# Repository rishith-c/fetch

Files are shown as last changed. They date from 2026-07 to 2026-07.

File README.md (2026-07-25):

# FETCH

FETCH is a mecanum-wheeled robot that carries a trash can around a gallery and
comes to you when you call it. We built it in eight hours at a hackathon, and
it won first place.

You teach it a room by driving it around once. Park it on a spot, press a
button to name that spot, drive to the next one, name that. From then on it
drives to any of them on its own. A visitor calls it by opening a web page and
pointing their phone at the AprilTag beside them.

There is no lidar on this robot. No encoders, no IMU, and no map of the room.
That was not a design goal, it was the parts budget, and working around it is
most of what makes the project interesting.

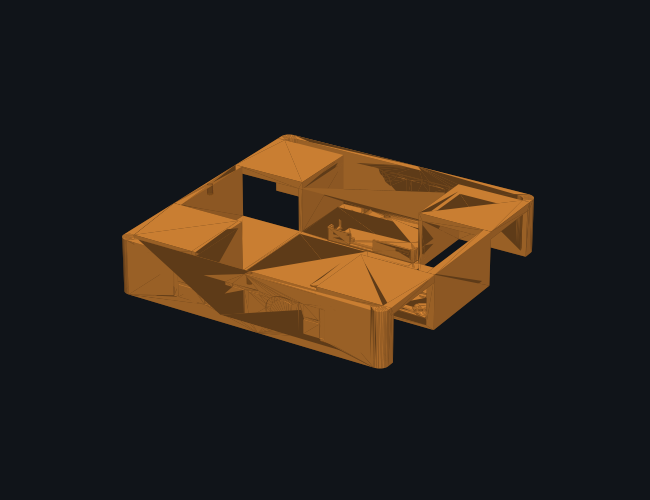
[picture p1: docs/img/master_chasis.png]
chassis


## The navigation problem

A robot with no encoders cannot know where it is. You might think you could
count motor steps and integrate, but mecanum wheels slip sideways as part of
how they generate lateral motion, so those counts diverge from reality within
a metre or two.

So we do not store positions. We store driving.

```
home ──teach──> tag 0 ──teach──> tag 1 ──teach──> tag 2
     <──────────        <──────────       <──────────
```

Nodes are places. Edges are the actual velocity commands you gave while
driving between them, saved as `(vx, vy, w, dt)` tuples. Press "mark 0" and
everything you drove since the last mark becomes the edge into node 0.

The nice part is that edges run both ways for free. To drive an edge backwards
you replay its segments in reverse order with every velocity negated. That is
a true inverse here, and we checked: net displacement of forward plus backward
comes out to exactly zero. It only works because the robot is holonomic. Try
this on a car and you will drive into a wall.

Route planning is Dijkstra weighted by recorded driving seconds. We started
with breadth-first search over hop count and it kept choosing one long edge
over two short ones, which looked broken to anyone watching.

## Calling the robot

Open `/user` on a phone, point the camera at a tag, press the button. The page
sends camera frames to the Pi, which runs the AprilTag detector and answers
with which checkpoint you are standing at. The robot then drives to you from
wherever it happens to be.

Detection runs on the Pi rather than in the browser, which is why this works
on any phone with no app and no install. The phone only needs a camera and a
fetch call.

## Hardware

| Part | What we used |
|---|---|
| Compute | Raspberry Pi 4 on its own 5 V power bank |
| Motion | Arduino Uno R4 WiFi, CNC Shield V3, four A4988 drivers |
| Motors | Four NEMA 17 steppers, 60 mm mecanum wheels |
| Sensing | USB webcam, three front-facing HC-SR04 |
| Power | 3S LiPo for motors, switched separately from the Pi |

The Pi and the motors run on separate supplies on purpose. Killing motor power
mid-demo should not take down the computer, the web server, and your only way
of stopping the robot.

Motor wiring:

| Corner | Socket | Step | Dir | Polarity |
|---|---|---|---|---|
| Front left | X | D2 | D5 | +1 |
| Front right | Y | D3 | D6 | +1 |
| Rear left | Z | D4 | D7 | -1 |
| Rear right | A | D12 | A0 | +1 |

Rear right takes its direction signal from A0 on a jumper wire rather than the
usual pin.

## Printed parts

Five parts, about five hours of printing all together, which ran while we
wrote firmware. The chassis is the long pole by a wide margin, so print that
one first and do everything else while it runs.

| | Part | Size (mm) | Print time | Filament |
|---|---|---|---|---|
|  | Master chassis | 210 x 210 x 55 | 3 h 51 m | 221 cm3 |
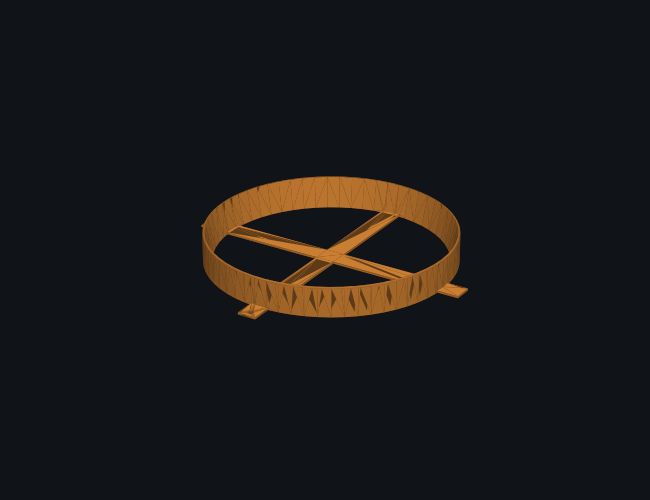
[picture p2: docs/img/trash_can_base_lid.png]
|  | Trash can base lid | 214 x 214 x 30 | 47 m | 48 cm3 |
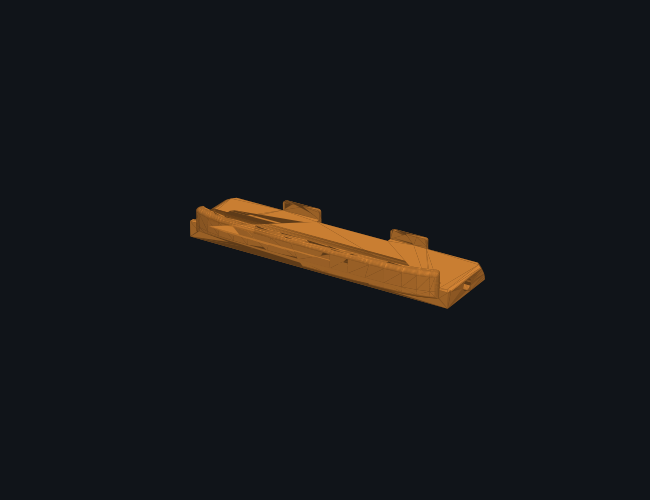
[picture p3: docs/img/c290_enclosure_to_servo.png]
|  | C290 enclosure to servo | 93 x 28 x 15 | 11 m | 9 cm3 |
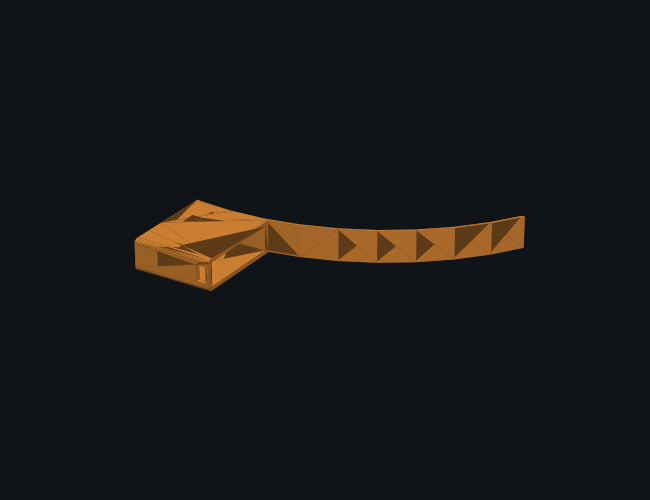
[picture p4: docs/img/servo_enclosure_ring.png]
|  | Servo enclosure ring | 106 x 88 x 16 | 10 m | 8 cm3 |
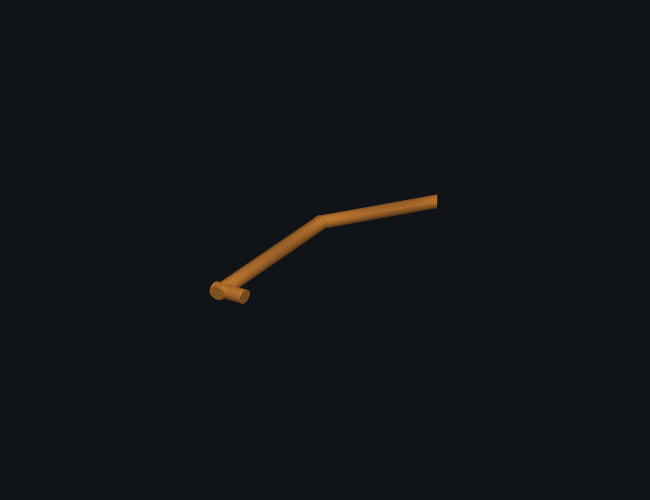
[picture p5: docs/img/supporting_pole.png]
|  | Supporting pole | 24 x 81 x 5 | 1 m | 1 cm3 |

Times are what our printers actually did at 0.3 mm layers and 15 percent
infill. A slower machine will take considerably longer, so slice before you
commit to a schedule.

## How much of this was fixed with a knife

We modeled these in a hurry and it shows. Roughly 80 percent of the parts
needed cutting or modifying by hand before they would fit. Holes drilled out,
walls trimmed, mounting faces filed back. Print quality was poor at the speed
we ran, so tolerances that would have been fine on a careful print were not
close enough to assemble.

Three of the four chassis joints needed super glue and repair work to hold.
The robot that won is held together partly with adhesive and partly with
patience.

Some features did not survive at all. The camera was supposed to sit on a tilt
servo so it could sweep to find a tag and then hold it centred. The mount
never fit properly, the servo never moved reliably, and we cut the whole
feature and bolted the camera down at a fixed angle. That turned out fine, and
arguably better, since a fixed camera is one less thing to fail mid demo.

If you are rebuilding this, dry fit the chassis before committing to the rest.
Most of what we cut by hand was avoidable with one test print and an hour of
tolerance work.

## Software

Three languages, each where it belongs.

Step timing lives on the Arduino in C++, because steppers need pulses at
precise intervals and Linux is not a real-time OS. A scheduler hiccup on the
Pi would stutter the motors. The Arduino does nothing else, so it never
hiccups.

Everything else is Python on the Pi: the web server, the checkpoint graph, the
route planner, and the vision. The web pages are HTML, CSS and JavaScript
embedded directly in `gui.py` as string constants.

The server is `http.server` from the Python standard library. No Flask, no
FastAPI, no build step. The whole thing is one file you copy with `scp`, and
on a fresh Pi it runs immediately. During a hackathon where the Pi got power
cycled repeatedly, that mattered more than any framework feature would have.

It has to be threaded because the camera stream at `/camera.mjpg` never
returns. It holds the connection open and writes JPEG frames forever, so a
single-threaded server would block there and stop answering everything else.
Five threads run in one process: HTTP handlers, the serial reader, a keepalive,
the camera, and the navigator.

One process rather than several, because only one process can hold
`/dev/ttyACM0` and only one can hold `/dev/video0`. Splitting autonomy into a
separate script would have meant stopping the GUI to demo, which is not a demo.

## Serial protocol

The Pi talks to the Arduino in plain text at 115200 baud.

```
v <vx> <vy> <w>   velocity, -100 to 100 each
m <corner> <spd>  drive one motor alone, 0=FL 1=FR 2=RL 3=RR
k <steps/s>       full scale wheel rate, for tuning stepper noise
g <0|1>           arm or disarm the front obstacle veto
s                 stop
?                 report state
```

Text rather than binary so you can debug it by opening a serial monitor and
typing. That saved us an hour when the rear right motor was misbehaving.

The Arduino reports `us f=52 lf=110 rf=0` in centimetres about eleven times a
second.

## Safety

Two of these live in firmware, which matters more than it sounds. The Pi
resends the current velocity every 100 ms, and if the Arduino goes 500 ms
without hearing anything it stops the motors. WiFi dropping, the browser
closing, the tunnel dying, or the Pi losing power all produce the same result:
the robot stops within half a second. The guarantee does not depend on the
network, because it is enforced by the side that is not on the network.

In precedence order:

1. The STOP button
2. Touching manual controls, which cancels any autonomous trip
3. The 500 ms communication watchdog, in firmware
4. Forward motion refused under 25 cm of front clearance, in firmware
5. Obstacle pause during route replay, which resumes rather than skipping

A sonar reading of `0` means no echo, not an obstacle. Both the firmware veto
and the replay loop require a reading that is close and physically plausible,
at least 3 cm, so a disconnected sensor cannot freeze the robot in place. We
learned this the hard way when a rail glitch pinned the front sensor at 5 cm
and forward motion stopped working entirely.

## Repository layout

```
firmware/fetch_final/   Arduino sketch: kinematics, sonar, safety
pi/gui.py               web server, both pages, all endpoints
pi/checkpoints.py       place graph, teaching, Dijkstra routing
pi/navigator.py         replays a planned chain of edges
pi/drive.py             serial to the Arduino, keepalive, auto reconnect
pi/fetch_auto.py        camera and AprilTag detection
cad/                    the five printed parts
markers/                printable tag36h11 tags, 0 through 4
bringup.sh              starts everything and prints both URLs
```

## Running it

```bash
./bringup.sh
```

This waits for the Pi, checks both services, reads the current tunnel URL, and
confirms both pages return 200 before printing anything. The services start
themselves at boot, so after a power cycle you only need this to find out what
URL the tunnel picked.

Print `markers/apriltags/apriltags_0-4.pdf` at 100 percent scale. Do not let
the print dialog scale it to fit the page, because the tag size is how the
robot judges distance.

## What it does not do

Replay is open loop, so every edge adds a few percent of distance error plus
some heading drift, and it compounds along a chain. The fix is teaching
checkpoints every couple of metres so no single edge is long enough to matter.

The robot has no spatial model, so it cannot work out that two checkpoints are
near each other unless you drove between them. If it insists on routing from 1
back through home to reach 0, drive it from 1 to 0 once and mark it. That edge
then exists in both directions.

Position is belief, not measurement. It updates when a trip completes, so an
aborted trip never claims an arrival, but picking the robot up and moving it
makes the belief wrong. Press Set HOME to correct it.

It does not plan around a moving crowd. It stops for obstacles and resumes.
That is honest for a supervised indoor space, which is what it was built for.

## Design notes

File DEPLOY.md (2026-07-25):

# FETCH — End-Product Software Deployment

Stepper build (NEMA17 + CNC Shield V3). One firmware, one Pi stack, one path.

## The software map

| Piece | File | Job |
|---|---|---|
| Firmware (THE one to flash) | `firmware/fetch_final/fetch_final.ino` | 4 steppers + 5 sonars + tilt servo + serial protocol + watchdog + front veto |
| Pi relay | `pi/fetch_relay.py` | phone WiFi vectors -> USB serial (phone-sees-robot homing) |
| Direct-path nav | `pi/topo_nav.py` | checkpoint graph router (BFS over verified segments) |
| Checkpoint server | `pi/topo_server.py` | iPhone QR destination -> AprilTag route -> drives the Uno |
| Bench tester | `pi/fake_phone.py` | simulates the phone stream, no app needed |
| Service installer | `pi/install_fetch_service.sh` | auto-start on boot via systemd |

## 1. Flash the firmware (from this Mac, robot USB-connected)

```bash
arduino-cli compile -b arduino:renesas_uno:unor4wifi ~/Developer/fetch/firmware/fetch_final
```

```bash
arduino-cli upload -b arduino:renesas_uno:unor4wifi -p /dev/cu.usbmodemB43A45B3E0482 ~/Developer/fetch/firmware/fetch_final
```

If upload fails: double-tap RESET (LED breathes) and retry.
Then Serial Monitor 115200: `f b l r q e s` drive keys, `t 120` tilts camera,
`us f=.. lf=..` lines stream distances.

## 2. SSH into the Pi

Enable once (SD card in this Mac): create an empty file named `ssh` on the
boot partition. Or on the Pi itself: `sudo raspi-config` -> Interface Options -> SSH.

```bash
ssh pi@raspberrypi.local
```

(Default password `raspberry` unless you changed it. If .local fails, find the
IP in your hotspot's client list and `ssh pi@<ip>`.)

## 3. Deploy the code to the Pi

```bash
scp -r ~/Developer/fetch/pi pi@raspberrypi.local:~/fetch
```

On the Pi (one time):

```bash
sudo apt update && sudo apt install -y python3-serial python3-opencv python3-pip && pip3 install pupil-apriltags --break-system-packages
```

## 4. Run it

Plug the Uno into the Pi via USB. Manual/bench test first:

```bash
python3 ~/fetch/fake_phone.py --approach
```

Phone-vision homing (the app streams to this):

```bash
python3 ~/fetch/fetch_relay.py
```

Direct-path checkpoint navigation (press-button-and-it-comes, out of sight):

```bash
python3 ~/fetch/topo_server.py --serial /dev/ttyACM0 --map ~/fetch/config/topo_map.demo.json --start-zone 0
```

## 5. Auto-start on boot (demo day)

```bash
bash ~/fetch/install_fetch_service.sh --serial /dev/ttyACM0 --start-zone 0 --dry-run
```

Re-run without `--dry-run` to install. Robot then boots straight into service.

## Protocol (Uno <-> Pi), for debugging

- Pi -> Uno: `v vx vy w\n` at up to 15 Hz (each -100..100), `t <deg>\n` tilt
- Uno -> Pi: `us f=52 lf=110 rf=200 lr=0 rr=88\n` at ~7 Hz (cm, 0 = no echo)
- Uno stops itself if `v` goes silent 500 ms (watchdog) and refuses forward
  motion under 25 cm front clearance (veto) — safety lives on the Uno.

## Wiring recap for fetch_final

- Motors (proven): FL=X(2,5) FR=Y(3,**A2**) RL=Z(4,7) RR=A(12,13), EN=8
- Sonars: TRIG all -> D9. Echoes: front D10, L-front A0, R-front A1,
  L-rear A3, R-rear A4
- Servo: signal D11, power from XL4015 @5.0V (never the Uno 5V), common GND
- POL / corner fixes: edit `POL[4]` and the four constructors at the top of
  fetch_final.ino only.

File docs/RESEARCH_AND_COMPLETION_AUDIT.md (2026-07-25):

# FETCH research and completion audit

Last software audit: 2026-07-23. Final selected prototype: TT mecanum chassis,
Uno R4, two L298N modules, two 6.5 V XL4015 rails, five HC-SR04 sensors, Pi 4
camera navigation, and the iPhone checkpoint app.

## Requirement interpretation

“Press a button when neither I nor the robot can see the other, and have the
robot come to me” is implemented as **checkpoint rendezvous**:

1. The person scans the QR on the nearest mapped poster.
2. The app sends that fixed checkpoint ID to the robot over private Wi-Fi.
3. The robot independently sees AprilTags with its forward camera and follows a
   pre-commissioned directed graph.
4. The person and robot never need line of sight to one another.
5. The final tag plus front-sonar range proves arrival at the poster.

This does not infer the phone's indoor coordinates and does not track a moving
person. That distinction is fundamental: without venue infrastructure, a phone
does not provide reliable mall-scale indoor position to this robot. A scanned
known checkpoint turns an underdetermined localization problem into a bounded
routing problem suitable for the hackathon.

## Research decisions

| Topic | Primary evidence | Decision in this build |
|---|---|---|
| Visual fiducials | [AprilTag 3 project](https://github.com/AprilRobotics/apriltag) documents small-tag improvements and OpenCV integration; [OpenCV ArUco detection](https://docs.opencv.org/4.x/d5/dae/tutorial_aruco_detection.html) provides dictionary-based marker detection. | Use OpenCV's built-in `DICT_APRILTAG_36h11` end-to-end so poster generation and Pi detection use the identical available family. Use a measured 180 mm tag and require route camera tests. |
| Camera geometry | Pinhole projection from the requested 1280 px width and assumed 70° horizontal FOV. | A 180 mm tag models as 54.8 px at 3 m. The Pi rejects a camera stream below 1280×720. Initial checkpoint spacing is 2–3 m; 5 m is only an experimentally proven extension. |
| Ultrasonic timing | [HC-SR04 datasheet](https://www.digikey.in/en/htmldatasheets/production/1979760/0/0/1/hc-sr04.html) specifies a 10 µs trigger, 40 kHz burst, nominal 2–400 cm range, and recommends a measurement cycle over 60 ms. | Trigger all five for 10 µs every 65 ms and capture all five echoes concurrently. Installed cross-talk testing remains mandatory. |
| Uno electrical/pins | [Arduino Uno R4 Minima datasheet](https://docs.arduino.cc/resources/datasheets/ABX00080-datasheet.pdf) identifies 5 V operation, PWM-capable pins, analog pins usable as GPIO, and per-pin current limits. | Use PWM D5/D6/D9/D10, eight other motor-direction GPIO, D3 shared trigger, and D11/A2–A5 echoes. L298 logic inputs—not motors—load the GPIO. |
| Motor driver loss | [ST L298 datasheet](https://www.st.com/resource/en/datasheet/l298.pdf) gives a typical total bridge drop of about 1.8 V at 1 A and larger worst-case drops, logic supply requirements, current limits, and thermal protection. | Two L298Ns are accepted because they are already selected, but they are inefficient and require measured current/heat. A 6.5 V driver rail yields about 4.7 V at a typical 1 A bridge load. |
| DC conversion | [XL4015 datasheet](https://www.xlsemi.com/datasheet/XL4015-EN.pdf) specifies an adjustable step-down regulator and headline 5 A capability under suitable implementation/thermal conditions. | Use two modules, one per L298N, never paralleled. Adjust each unloaded to 6.50 V and validate voltage and temperature under final load. Module marketing is not accepted as proof of continuous current. |
| Chassis/motors | [Hiwonder chassis listing](https://www.hiwonder.com/products/mecanum-wheel-smart-chassis-car) specifies four 3–6 V 1:120 TT motors, 120–240 RPM, 66 mm wheels, 180 × 140 × 89 mm chassis, and a claimed 1500 g capacity. | Treat 3–6 V and 1500 g as bounds that still require assembled payload and traction tests. |
| Pi power | [Raspberry Pi power documentation](https://www.raspberrypi.com/documentation/computers/raspberry-pi.html) specifies the Pi 4's recommended 5.1 V / 3 A supply. | Use a separate power bank for Pi/camera/Uno compute; keep noisy motor power on the battery/converters. Grounds meet through Pi USB→Uno→L298 logic. |
| iPhone local network | Apple requires a [local-network usage description](https://developer.apple.com/documentation/BundleResources/Information-Property-List/NSLocalNetworkUsageDescription) and documents [`NSAllowsLocalNetworking`](https://developer.apple.com/documentation/bundleresources/information-property-list/nsapptransportsecurity/nsallowslocalnetworking) for `.local`/local resources. | Generated Xcode project contains both keys. The app uses `http://fetch.local:8080` on a private demo router/hotspot. Internet-wide ATS is not disabled. |
| Battery connector | The pack seller has not supplied an independently verified BMS-current or connector-current specification. | Begin with a 3 A fuse, use only the matching charger, never parallel packs, measure real current/heat, and do not increase the fuse without exact component ratings. |

## Software evidence

`./verify_all.sh` currently proves:

- 13/13 deterministic pin, camera, stopping-envelope, runtime, converter, and
  L298 voltage calculations pass.
- 16/16 navigation, multi-hop out-of-sight routing, directed-graph, stale-data, arrival, obstacle, serial,
  heartbeat, and live HTTP API tests pass.
- `tt_fetch_drive.ino` compiles for Uno R4 Minima at 18% flash and 13% RAM.
- Pi server, navigation, and map tools compile; a sample graph validates.
- Swift source typechecks and the generated Xcode project builds for an iOS
  Simulator target with required permission keys.
- All 12 generated AprilTags detect and all 12 QR payloads decode.
- The README, verifier, firmware, Pi service, app, posters, and final manual all
  name the same two-L298N baseline.

These checks are authoritative evidence for software structure and deterministic
models only. They are not evidence of physical performance.

## Requirement-by-requirement status

| Objective requirement | Evidence | Status |
|---|---|---|
| App selects where the person is | QR parser accepts only `FETCH:<nonnegative id>`; generated posters encode matching payloads. | Software proven |
| Button summons while robot is out of sight | App `POST /come`; HTTP integration test; route runs from current checkpoint to requested ID without person/robot line of sight. | Software proven; venue route pending |
| Robot knows where it is | It starts at an operator-confirmed `--start-zone` and updates `at` only after gated tag arrival. Fresh visible tags support localization search. | Software proven; camera route pending |
| Robot knows how to reach every checkpoint | Directed BFS plus strong-connectivity validation. | Software proven; physical directed edges pending |
| Robot follows wall codes | OpenCV AprilTag detector, centered visual steering, 1280×720 preflight, regenerated tags. | Software proven; actual camera/lighting pending |
| Obstacle is not confused with arrival | Arrival requires correct tag area, centering, 65±12 cm sonar, and 0.35 s hold; close small-tag obstacle test passes. | Software proven; physical obstacle test pending |
| Loss of Pi commands stops motors | Uno 500 ms watchdog. | Code/compile proven; unplug test pending |
| Loss of camera/telemetry stops route | 0.5 s freshness checks and tests. | Software proven; hardware disconnect tests pending |
| Loss of phone stops route | 2 s server heartbeat watchdog and integration test. | Software proven; real Wi-Fi/app-background test pending |
| Two L298Ns and five sonars fit Uno | 18 unique GPIO signals, correct PWM set, no overlap, firmware compiled. | Proven electrically at signal-map level |
| Battery runs 20 minutes | Energy model predicts 32 minutes even at 3 A using 80% capacity. | Model only; loaded 20-minute run pending |
| Electrical path is safe enough for demo | Fused, switched, isolated motor rails, separate Pi rail, common ground, required capacitors/jumpers documented. | Design reviewed; measurements/thermal pending |
| Entire supervised hackathon demo works | 1–150 manual and go/no-go sheet define exact acceptance. | **Not yet proven physically** |

## Hard limits and residual risks

- HC-SR04 has no diagnostic distinction between open space and a disconnected or
  acoustically failed sensor; preflight targets and an operator cutoff are
  therefore required.
- Five simultaneous ultrasonic transmitters can cross-talk. If installed tests
  show unsafe false clears, the hardware must change; software cannot certify it.
- L298N voltage loss and TT stall current are highly load-dependent. The exact
  motor stall current and pack BMS rating remain unknown until measured/sourced.
- No wheel encoders or IMU exist. The robot can visually home between tags but
  cannot guarantee a metrically accurate path through an unmarked blind segment.
- The graph is only valid for the exact poster positions, camera height, lighting,
  and cleared straight segments that were commissioned.
- Guest mall Wi-Fi may isolate clients. Use a private travel router/hotspot whose
  full-route coverage has been tested.
- HTTP control is unauthenticated and intentionally limited to a private demo
  network. It is not a production security architecture.
- Five hobby sonars and software stops do not constitute certified personnel
  protection. Keep the route controlled and an operator on the physical switch.

## Completion rule

The objective is complete only after every blank in the final manual's go/no-go
record contains measured evidence from this exact assembled robot and every
source-to-destination summon passes in the actual demo layout. Until then the
correct claim is **software-verified, physically pending**.

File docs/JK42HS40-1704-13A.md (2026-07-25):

---
tags: [hardware, motor, final]
---
# JK42HS40-1704-13A

Final FETCH motor. Manufacturer: JKONGMOTOR.

| Specification | Value |
|---|---:|
| Type | NEMA17, 2-phase bipolar, 4-wire |
| Step angle | 1.8° = 200 steps/revolution |
| Rated current | 1.7A per phase |
| Phase resistance | 1.5Ω |
| Phase inductance | 2.3mH |
| Holding torque | 0.42Nm |
| Body | 42×42×40mm |
| Shaft | 5mm D-cut |
| Mass | approximately 280g |
| Manufacturer coil colours | A+: black, A−: green, B+: red, B−: blue |

Verify coil pairs with multimeter continuity even when colours match.

## A4988 setting

The 75% target is 1.275A. Vref remains:

| Sense resistor | Vref |
|---|---:|
| R050 | 0.510V |
| R100 | 1.020V |

Use forced airflow. Never connect or disconnect a motor while powered.

## Recalculated result

- Estimated acceleration under the project assumptions: approximately 4,000mm/s².
- Firmware slew: 500mm/s², approximately 8× conservative.
- The 2.3mH inductance gives ample margin at the final 250mm/s ceiling.

Source: [JKONGMOTOR manufacturer specification](https://www.jkongmotor.com/nema-17-jk42hs40-1704-13a-hybrid-stepper-motor.html).

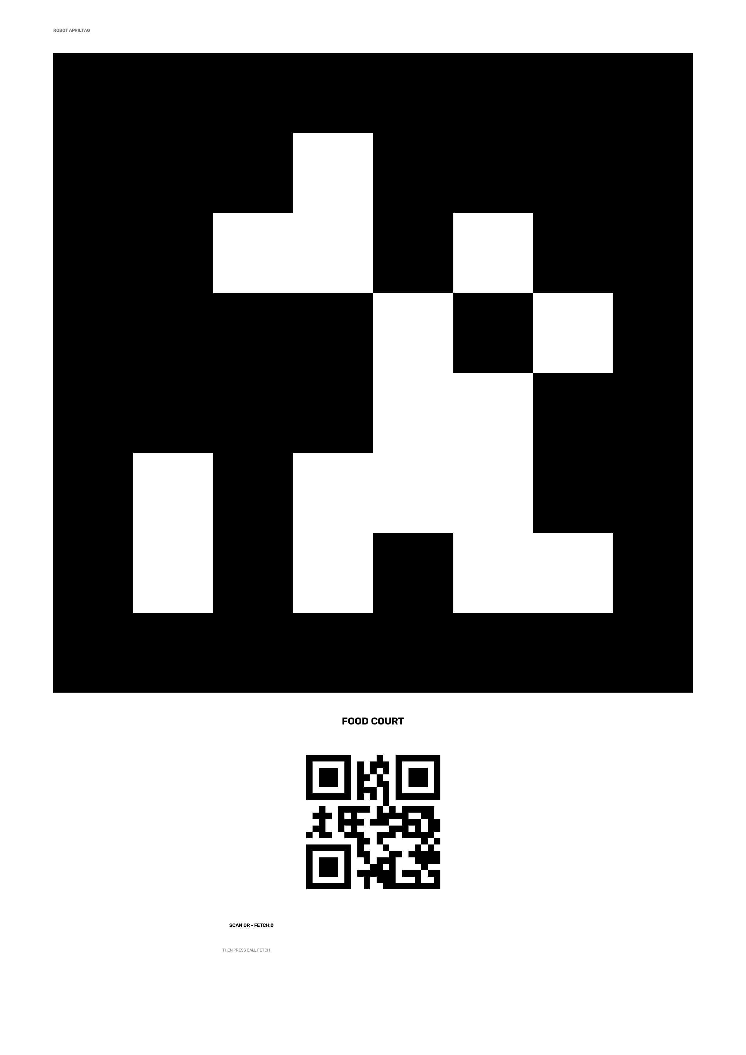
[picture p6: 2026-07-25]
markers/checkpoint_sample.png

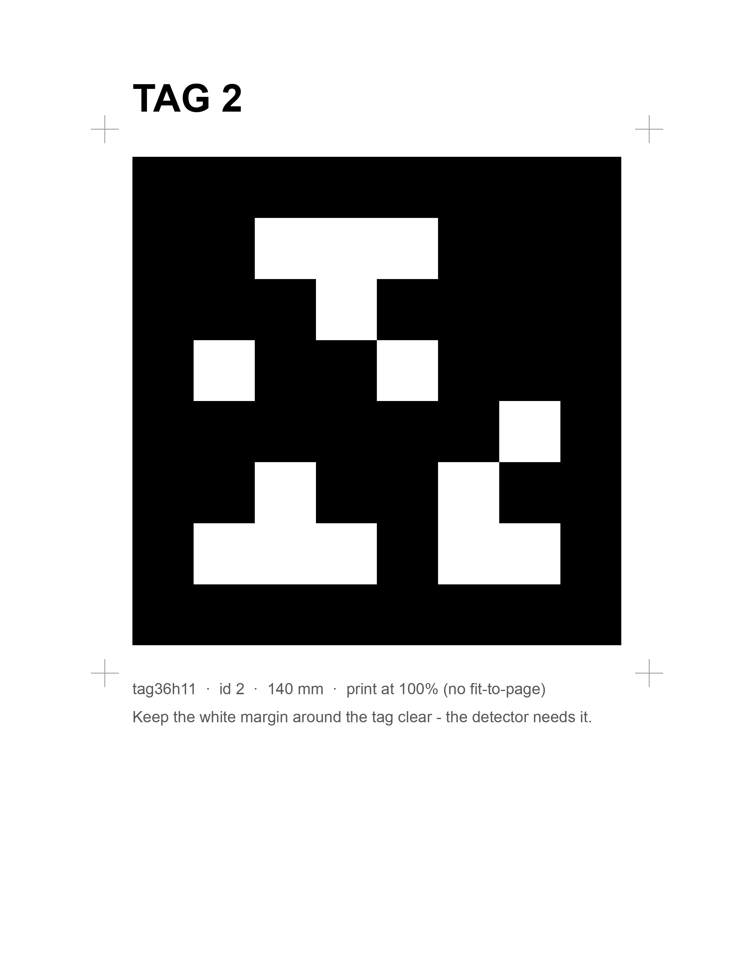
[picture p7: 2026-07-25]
markers/apriltags/apriltag_2.png

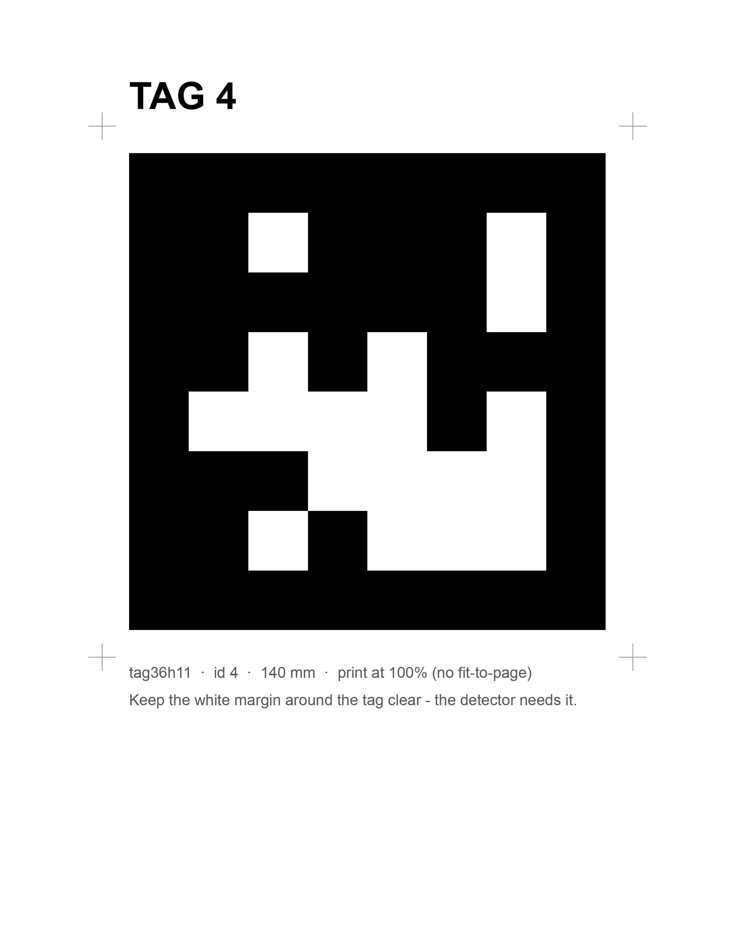
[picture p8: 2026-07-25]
markers/apriltags/apriltag_4.png

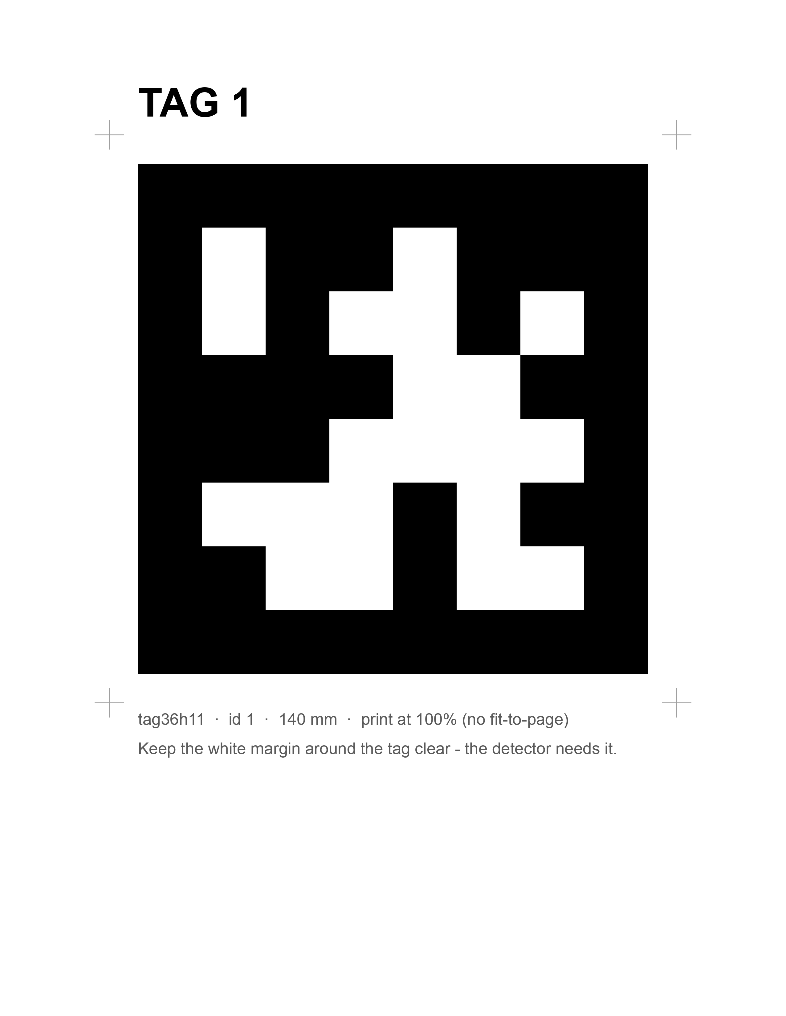
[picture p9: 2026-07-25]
markers/apriltags/apriltag_1.png

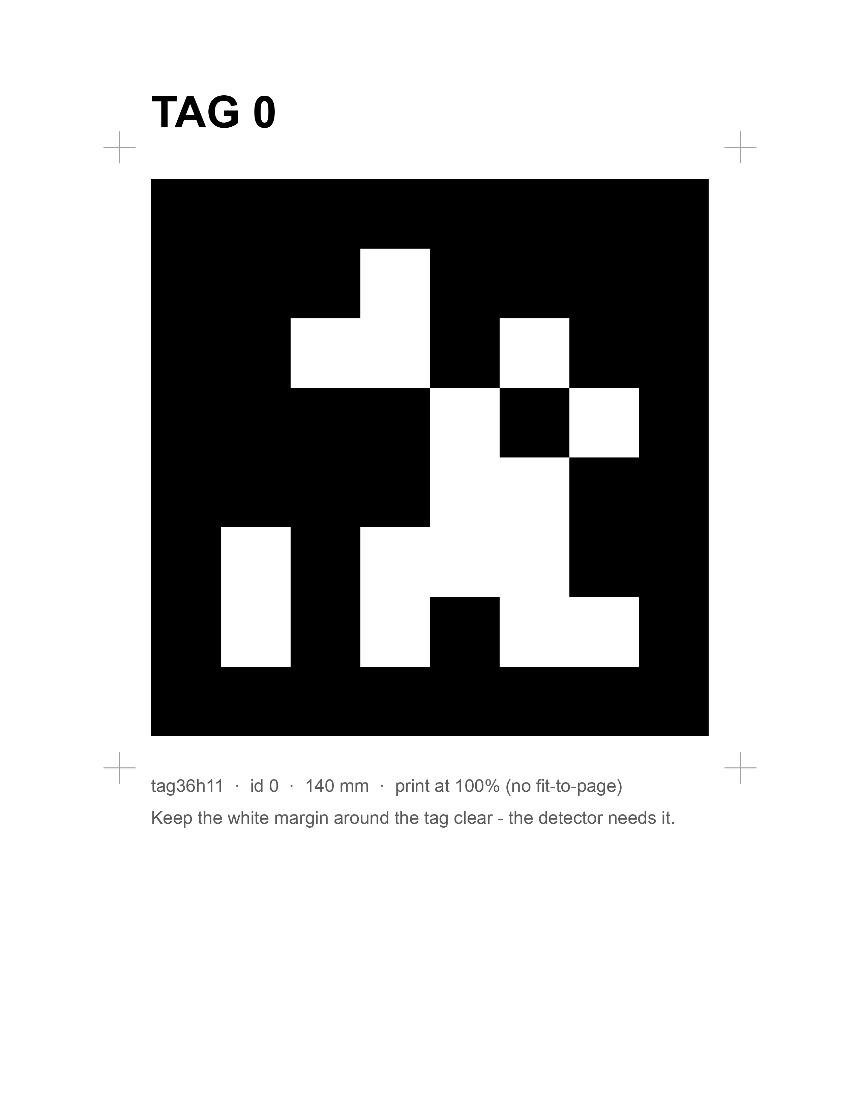
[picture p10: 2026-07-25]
markers/apriltags/apriltag_0.png

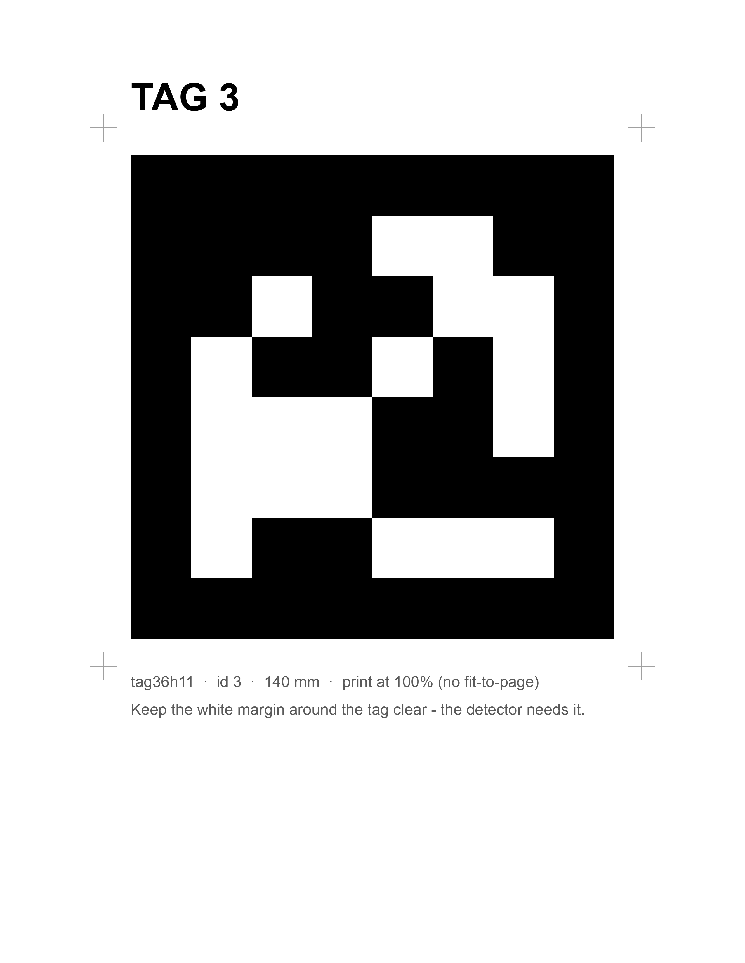
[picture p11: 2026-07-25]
markers/apriltags/apriltag_3.png

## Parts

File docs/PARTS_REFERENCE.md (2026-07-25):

# FETCH — verified parts reference

Every number here is from a manufacturer datasheet or the chip/board spec, with
sources at the bottom. Cross-checked July 2026.

## Motor — JK42HS40-1704-13A (NEMA 17)
| Spec | Value |
|---|---|
| Step angle | 1.8° → **200 steps/rev** |
| Phases / wires | 2 phase, 4 wire (bipolar) |
| Rated current | **1.7 A / phase** (peak) |
| Rated voltage | 2.55 V |
| Phase resistance | 1.5 Ω ±10% |
| Phase inductance | 2.3 mH ±20% |
| Holding torque | **0.42 N·m** (4.2 kg·cm) |
| Body | 42 × 42 × ~40 mm |
| Weight | ~0.24–0.28 kg |
| Shaft | 5 mm, D-cut |

### Wire → coil map (THE thing that stops the vibration)
| Wire | Function | Coil | Goes to driver pair |
|---|---|---|---|
| **Black** | A+ | **Coil A** | 1A / 1B |
| **Green** | A− | **Coil A** | 1A / 1B |
| **Red** | B+ | **Coil B** | 2A / 2B |
| **Blue** | B− | **Coil B** | 2A / 2B |

Each driver pair gets **both wires of one coil**. Split a coil (e.g. Black+Red
in one pair) → motor vibrates, won't turn. **Verify with a multimeter:** the two
wires reading ~1.5 Ω together are one coil (colors vary between batches).

## Driver — A4988, R100 sense resistors
| Spec | Value |
|---|---|
| Sense resistor (your board) | **R100 = 0.100 Ω** |
| **Vref target** | **1.02 V** ( = 1.275 A = 75% of 1.7 A ) |
| Formula | Vref = I × 8 × Rsense = 1.275 × 8 × 0.100 |
| VMOT range | 8–35 V (11.1 V pack is fine) |
| Current limit | ~1 A bare, ~1.5 A with heatsink, 2 A with airflow |
| Microstep (1/4) | **MS2 jumper ONLY** (MS1 off, MS3 off) — same on all four. MS1+MS2 = 1/8, not 1/4 |
| Motor pins | 1B 1A 2B 2A → coil A = 1A/1B, coil B = 2A/2B |

If your board were R050 the target would be 0.51 V; R200 → 2.04 V. **Yours is
R100 → 1.02 V.**

## Shield — CNC Shield V3
| Socket | STEP | DIR | Wheel |
|---|---|---|---|
| X | D2 | D5 | front-left |
| Y | D3 | D6 | front-right |
| Z | D4 | D7 | rear-left |
| A | D12 | D13 | rear-right (set bottom-left jumpers to D12/D13) |

- Enable: **D8** (LOW = drivers on)
- Motor power terminal silkscreen says 12–36 V; the A4988 chip itself is 8–35 V.

## Board — Arduino Uno R4
| Spec | Value |
|---|---|
| MCU | Renesas RA4M1, 48 MHz, 32-bit |
| Flash / RAM | 256 KB / 32 KB |
| Logic level | 5 V |

## Golden rules (each one kills an A4988)
1. **Never connect/disconnect a motor with power on** — the coil spike blows the driver.
2. **Set Vref with the motor disconnected**, USB power only, 12 V off.
3. **Check driver orientation** before powering — backwards = instant death.

## Sources
- Motor datasheet — [JKONGMOTOR JK42HS40-1704-13A](https://www.jkongmotor.com/nema-17-jk42hs40-1704-13a-hybrid-stepper-motor.html)
- Motor specs — [Abra Electronics JK42HS40-1704](https://abra-electronics.com/electromechanical/motors/stepper-motors/nema-17/jk42hs40-1704.html), [anodas.lt](https://www.anodas.lt/en/stepper-motor-jk42hs40-1704-200-steps-rev-2-8v-1-7a-0-4nm)
- A4988 + CNC Shield pinout — [Envistia Mall CNC Shield V3 guide](https://envistiamall.com/blogs/learn/cnc-expansion-shield-v3-for-a4988-and-drv8825-stepper-motor-drivers-user-guide), [makerguides A4988 tutorial](https://www.makerguides.com/a4988-stepper-motor-driver-arduino-tutorial/)

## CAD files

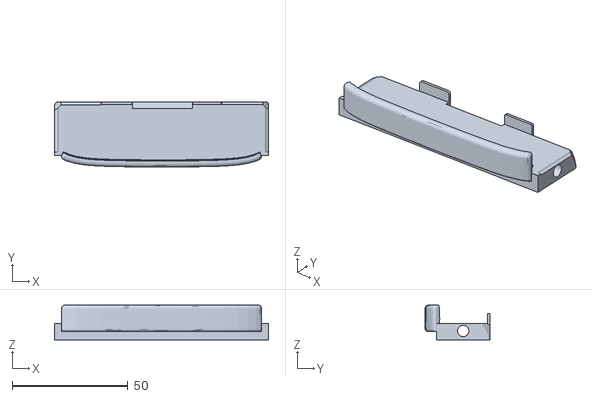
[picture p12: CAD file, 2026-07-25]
cad/C290 enclosure to Servo.stl
92.6 x 28.2 x 15.1

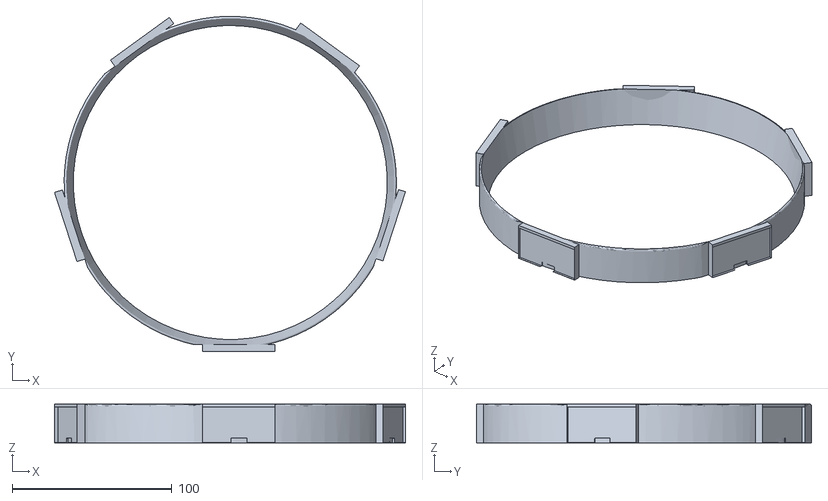
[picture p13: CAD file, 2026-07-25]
Ultrasonic Ring.stl
220.0 x 210.1 x 24.3

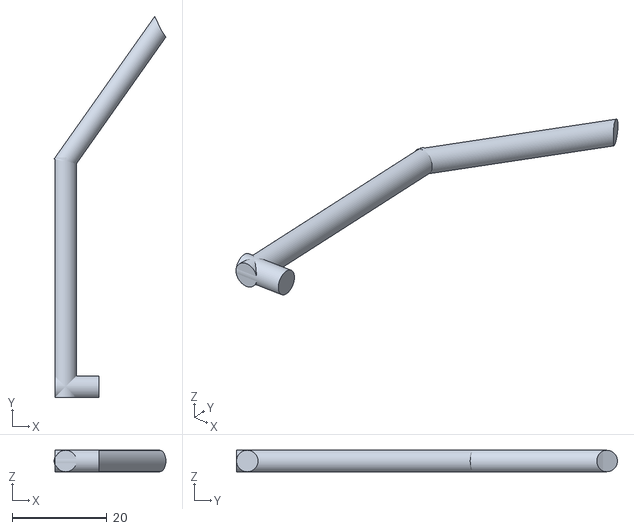
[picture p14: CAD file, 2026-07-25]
cad/Supporting pole.stl
23.6 x 80.5 x 4.55

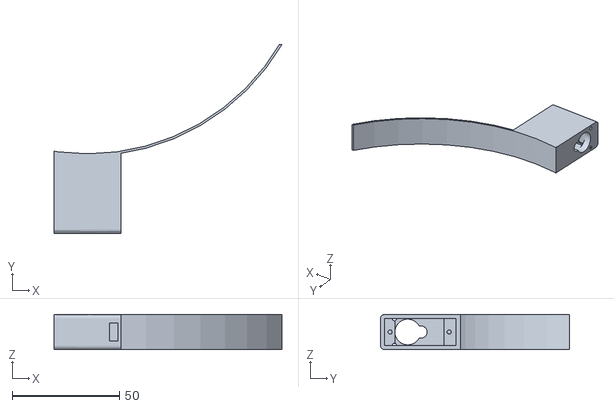
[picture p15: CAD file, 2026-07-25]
cad/Servo enclosure ring.stl
106.1 x 88.1 x 16.4

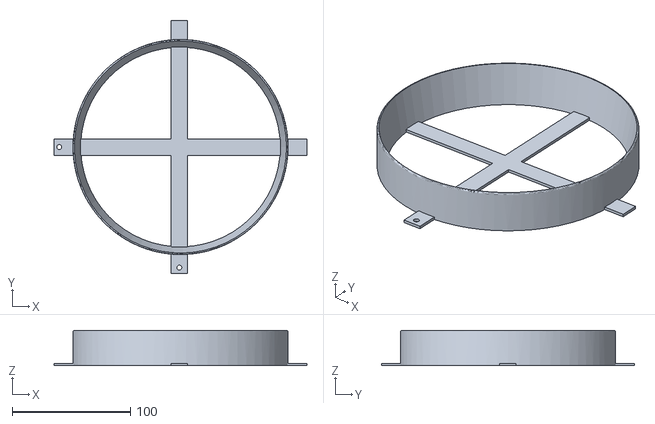
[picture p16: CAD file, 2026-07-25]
cad/Trash can base lid.stl
214.0 x 214.0 x 30.0

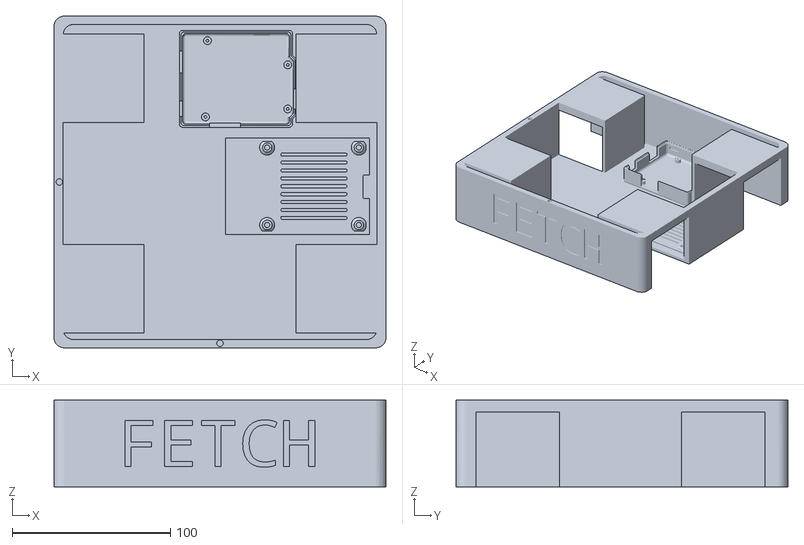
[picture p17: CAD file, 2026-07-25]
cad/Master Chasis.stl
210.0 x 210.0 x 55.0

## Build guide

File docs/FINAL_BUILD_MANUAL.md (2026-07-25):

# FETCH final build and commissioning manual

**Baseline:** Hiwonder TT-motor mecanum chassis, Uno R4, two L298N modules, two
XL4015 converters, five HC-SR04 sensors, Pi 4 + USB camera, iPhone checkpoint
app, and HomeJoy 11.1 V 2000 mAh Li-ion battery.

This is the only final build described here. Do not mix in the archived CNC
Shield, A4988, NEMA, L293D, TF-Luna, servo, or battery-monitor designs.

## What the completed demo does

The person scans the QR on the nearest checkpoint and presses **CALL FETCH**.
The phone sends `zone=<id>` to the Pi. The robot can begin out of sight. It
localizes from a visible AprilTag, finds a route through a strongly connected
directed checkpoint graph, then visually approaches each next tag. The Uno
stops locally when ultrasonic clearance is unsafe. The last AprilTag, centered
and held at the expected sonar range, is the arrival proof.

The robot comes to the **scanned checkpoint**, not to an arbitrary unmarked
person. The app must remain open while it travels; losing the phone heartbeat
causes a stop. Use this only on a supervised, taped-off demo route.

## Required parts

1. Obtain one Hiwonder 180 × 140 × 89 mm mecanum chassis kit with four 3–6 V, 1:120 TT brushed motors and four 66 mm mecanum wheels.
2. Obtain one Arduino Uno R4 Minima.
3. Obtain exactly two standard L298N dual H-bridge modules.
4. Obtain one HiLetgo three-pack of adjustable XL4015 modules; install two and keep the third as a spare.
5. Obtain five genuine-working HC-SR04 modules.
6. Obtain one Raspberry Pi 4 and one forward-facing UVC USB camera.
7. Obtain one dedicated 5.1 V / 3 A Pi power bank and a short suitable cable.
8. Use one HomeJoy 11.1 V 2000 mAh Li-ion pack at a time and only its matching 3S charger.
9. Obtain one inline ATC/ATO blade-fuse holder and 3 A fuses.
10. Obtain one latching master power switch rated for at least 12.6 V DC and 5 A DC.
11. Obtain two 470 µF electrolytic capacitors rated at least 16 V.
12. Use short 18–20 AWG stranded copper for battery and motor-power branches, 22 AWG for motors, and 24–26 AWG for logic/sensors.
13. Use proper crimp splices or solder plus heat-shrink, insulated ferrules for screw terminals, cable ties, and strain relief.
14. Obtain a digital multimeter; a DC clamp meter or inline wattmeter is strongly recommended for commissioning.
15. Print the generated A4 checkpoint posters at 100% scale on matte paper and mount them rigidly.

## Reject incompatible substitutions

16. Do not use the L293D shield: its approximately 0.6 A continuous channel rating and voltage loss are a poor match for four loaded TT motors.
17. Do not use the old CNC Shield, A4988 drivers, or JK42HS40 NEMA motors with this wiring or firmware.
18. Do not feed 11.1–12.6 V directly into any TT motor.
19. Do not feed the motor battery directly into the Uno 5 V pin, Pi, camera, sonar, or L298 logic-5 V terminal.
20. Do not parallel the two XL4015 outputs; each converter powers only its assigned L298N motor-supply input.
21. Do not connect two battery packs together.
22. Do not use a fixed 5 V automotive converter for the L298 motor rail; the L298 bridge voltage drop would leave the motors underpowered.
23. Do not add a TF-Luna, camera-tilt servo, or battery monitor to this pin map.

## Mechanical assembly

24. Assemble the chassis and verify every mecanum roller turns freely.
25. Orient all four wheels according to the chassis manufacturer's mecanum X-pattern; photograph the finished orientation.
26. Label the motor locations `FL`, `FR`, `RL`, and `RR` before wiring.
27. Mount the battery low and centered, isolated from sharp metal edges.
28. Mount both L298N modules and both XL4015 modules where air can circulate and no conductive surface touches their undersides.
29. Mount the physical switch where an operator can reach it immediately.
30. Mount the fuse holder within 10 cm of the battery positive connector.
31. Mount the Pi, Uno, and camera rigidly; aim the camera level and straight forward.
32. Mount the front sonar facing forward.
33. Mount left-front and left-rear sonar modules facing left, separated as far as the chassis permits.
34. Mount right-front and right-rear sonar modules facing right, separated as far as the chassis permits.
35. Keep sonar transducers clear of wheels, cables, soft fabric, and angled chassis plates.

## Power wiring — battery disconnected

36. Identify battery positive and negative with the multimeter; never trust wire color alone.
37. Cut only a replaceable adapter lead if possible; do not cut the battery pack itself near its cells.
38. Connect battery positive to the inline 3 A fuse holder.
39. Connect the fuse-holder output to the master switch input.
40. Split the switched positive into two independent branches: XL4015 #1 `IN+` and XL4015 #2 `IN+`.
41. Split battery negative into XL4015 #1 `IN-`, XL4015 #2 `IN-`, L298N #1 GND, L298N #2 GND, and Uno GND.
42. Ensure the negative split makes one common reference among the motor battery, both converters, both L298Ns, and Uno.
43. Remove the `5V-EN` regulator jumper from both L298N modules.
44. Remove `ENA` and `ENB` jumper caps from both L298N modules so D5/D6/D9/D10 can provide PWM.
45. Leave both L298 motor-supply terminals disconnected while adjusting the converters.
46. Insert the 3 A fuse, turn on briefly, and set XL4015 #1 to exactly 6.50 V using the multimeter.
47. Set XL4015 #2 to exactly 6.50 V using the multimeter.
48. Turn power off and wait for both converter outputs to fall below 0.5 V.
49. Connect XL4015 #1 `OUT+`/`OUT-` only to L298N #1 motor `VS/+12V` and GND.
50. Connect XL4015 #2 `OUT+`/`OUT-` only to L298N #2 motor `VS/+12V` and GND.
51. Install one 470 µF capacitor directly across each L298 motor-supply input: capacitor `+` to 6.5 V and striped `-` to GND.
52. Connect Uno `5V` to both L298N logic `5V` terminals; the removed `5V-EN` jumpers prevent regulator conflict.
53. Power the Uno through its USB connection to the Pi; never power the Pi from the Uno.
54. Power the Pi only from the separate 5.1 V / 3 A power bank.
55. Confirm the Pi USB-to-Uno cable also provides the serial link and common logic ground.

## Exact motor-driver signal wiring

56. Connect L298N #1 channel A to motor `M1/FL`: `ENA=D5`, `IN1=D2`, `IN2=D4`.
57. Connect L298N #1 channel B to motor `M2/FR`: `ENB=D6`, `IN3=D7`, `IN4=D8`.
58. Connect L298N #2 channel A to motor `M3/RL`: `ENA=D9`, `IN1=D12`, `IN2=D13`.
59. Connect L298N #2 channel B to motor `M4/RR`: `ENB=D10`, `IN3=A0`, `IN4=A1`.
60. Connect each driver's two output terminals only to its assigned motor.
61. Tug-test every screw-terminal conductor and verify no loose strands bridge adjacent terminals.

| Motor | Position | PWM | Direction 1 | Direction 2 | Driver channel |
|---|---|---:|---:|---:|---|
| M1 | front-left | D5 | D2 | D4 | L298N #1 A |
| M2 | front-right | D6 | D7 | D8 | L298N #1 B |
| M3 | rear-left | D9 | D12 | D13 | L298N #2 A |
| M4 | rear-right | D10 | A0 | A1 | L298N #2 B |

## Exact ultrasonic wiring

62. Connect all five HC-SR04 `VCC` pins to Uno 5 V.
63. Connect all five HC-SR04 `GND` pins to the common Uno ground.
64. Connect all five `TRIG` pins together and connect the shared trigger wire to D3.
65. Connect front `ECHO` to D11.
66. Connect left-front `ECHO` to A2.
67. Connect right-front `ECHO` to A3.
68. Connect left-rear `ECHO` to A4.
69. Connect right-rear `ECHO` to A5.
70. Keep D0 and D1 unused.

All five modules transmit together because the direct L298 wiring consumes 12
GPIO. Firmware captures all echo pulses concurrently and repeats every 65 ms.
That meets the sensor's repeat-cycle guidance, but simultaneous modules can
still hear one another. Physical cross-talk testing is a mandatory acceptance
gate, not an optional improvement.

## Electrical inspection before first power

71. Remove the fuse and disconnect both the motor battery and Pi power bank.
72. Measure resistance between battery positive and negative on the robot side; investigate a near-short before continuing.
73. Verify continuity from every ground node to every other ground node.
74. Verify there is no continuity from 6.5 V rails to 5 V logic rails.
75. Verify converter outputs are not connected to one another.
76. Verify both `5V-EN` jumpers and all four `ENA/ENB` jumpers are physically removed.
77. Verify both capacitors have correct polarity.
78. Reinsert the fuse, keep all motors lifted off the floor, and switch on.
79. Measure both motor rails again: each must remain 6.3–6.7 V unloaded.
80. Measure Uno/sensor/L298 logic: 4.8–5.2 V.
81. Confirm the Pi shows no undervoltage warning on its separate supply.
82. Switch off immediately for odor, smoke, hot wiring, converter squeal, or unstable voltage.

## Load firmware and Pi software

83. Install the Arduino CLI/core or Arduino IDE with the Uno R4 Minima board package.
84. Flash `firmware/tt_fetch_drive/tt_fetch_drive.ino` to the Uno R4.
85. Open serial at 115200 baud and confirm `FETCH_TT_READY V3` plus `S` telemetry packets containing five ranges and one stop flag.
86. On the Pi run `sudo apt update`.
87. Install dependencies with `sudo apt install -y python3-opencv python3-serial avahi-daemon`.
88. Confirm `python3 -c "import cv2, serial; print(cv2.__version__, hasattr(cv2, 'aruco'))"` prints `True` for ArUco support.
89. Copy the repository to the Pi and connect the UVC camera and Uno USB cable.
90. Identify the Uno serial device with `ls -l /dev/serial/by-id/`; use that stable path instead of guessing `/dev/ttyACM0` when possible.
91. Put the iPhone and Pi on the same private hotspot or travel router; do not rely on mall guest Wi-Fi because client isolation may block phone-to-Pi traffic.
92. Park at a known checkpoint and start the server with `python3 pi/topo_server.py --serial /dev/serial/by-id/YOUR_UNO --map topo_map.json --start-zone 0 --host 0.0.0.0 --port 8080`, replacing `0` with the actual starting checkpoint.
93. Verify `curl http://127.0.0.1:8080/status` on the Pi reports fresh camera and telemetry before enabling floor motion.

After manual commissioning, install automatic startup from the Pi checkout:

```bash
bash pi/install_fetch_service.sh --dry-run \
  --serial /dev/serial/by-id/YOUR_UNO --map /absolute/path/topo_map.json --start-zone 0
sudo bash pi/install_fetch_service.sh \
  --serial /dev/serial/by-id/YOUR_UNO --map /absolute/path/topo_map.json --start-zone 0
```

The real invocation installs required Pi packages, sets the hostname to `fetch`,
enables Avahi and `fetch.service`, and prints the service status. The configured
start zone is a physical promise: after every boot, park the robot at that exact
checkpoint before allowing calls.

## Build the iPhone app target

94. Open the generated `ios/FetchCheckpoint.xcodeproj` in Xcode; regenerate it after editing `ios/project.yml` with `xcodegen generate --spec ios/project.yml`.
95. Confirm the target's generated Info.plist contains `NSCameraUsageDescription` for checkpoint QR scanning.
96. Confirm it contains `NSLocalNetworkUsageDescription` for nearby-robot control.
97. Confirm App Transport Security permits local-network HTTP only; the generated project uses `NSAllowsLocalNetworking`, not a broad Internet exception.
98. Select your development team, run on a physical iPhone, enter `http://fetch.local:8080`, and press **TEST CONNECTION**.
99. Keep the app foregrounded and the phone awake throughout a call; its 500 ms status polling is the route heartbeat.

## Print and map checkpoints

100. Run `python3 markers/make_checkpoints.py` using Python with OpenCV ArUco, Pillow, qrcode, and NumPy installed.
101. Print `markers/fetch_CHECKPOINTS_PRINT_ME.pdf` on A4 at **Actual Size / 100%** with no fit-to-page scaling.
102. Measure the black AprilTag square; reject the print unless it is 180 mm ±1 mm.
103. Start with checkpoints 2–3 m apart, approximately camera height, matte, flat, and well lit.
104. Keep each tag's surrounding white quiet zone unobstructed.
105. Use duplicate posters with the same checkpoint ID on angled/multi-face mounts if a checkpoint must be seen from different incoming directions.
106. Treat an edge `A→B` as valid only when the robot stopped at A can acquire B and the straight physical segment A-to-B is cleared.
107. If using `tools/make_topo_map.py --edges 0-1,1-2`, remember each hyphen creates both directions; physically test both `0→1` and `1→0`.
108. Validate that the graph is strongly connected so every checkpoint can route to every other checkpoint.
109. Do not place an edge around a blind corner, through a doorway that may close, or through normal pedestrian flow.

## One-wheel and mecanum commissioning

110. Keep the chassis lifted and send only stop commands at startup.
111. Command each motor forward one at a time and record actual wheel-face direction from the outside of that wheel.
112. Correct motor location only in firmware `CORNER`; correct direction only in firmware `POLARITY` or by swapping that motor's two output wires—not both.
113. Repeat until a positive forward command makes all four wheel-ground contact patches propel the chassis forward.
114. Test low-speed forward, backward, left strafe, right strafe, clockwise rotate, and counterclockwise rotate with the chassis still lifted.
115. Put the robot on the floor at minimum practical speed and repeat each primitive for one second with an operator at the switch.
116. Adjust only `TRIM` values in small increments if one motor is consistently stronger; do not conceal a mechanical bind with software.
117. Run the small mecanum circle test and confirm the chassis orientation remains approximately fixed; if it spins, stop and repair wheel placement/corner/polarity mapping before navigation.

## Mandatory sensor and navigation acceptance tests

118. Test every sonar alone against a large flat target at 20, 60, and 100 cm; require ±3 cm or document a stricter observed envelope.
119. Test all five operating together in their installed positions at the same distances and at angled walls; reject the shared-trigger layout if cross-talk produces unsafe false-clear readings.
120. Place obstacles just inside each programmed threshold and command motion toward them; every applicable direction must stop.
121. Cover the camera during a route; verify motor commands cease within one second.
122. Disconnect Uno USB during a route; verify the 500 ms firmware command watchdog stops motion.
123. Disable iPhone Wi-Fi or close the app during a route; verify the server stops motion approximately two seconds after heartbeat loss.
124. Press **STOP FETCH** during forward, strafe, and rotation; verify each stops.
125. Place an unrelated obstacle at 50 cm while the target tag is still small; verify the software reports blocked and never claims arrival.
126. At each checkpoint, verify arrival requires the correct target tag centered, sufficiently large, and front sonar near 65 cm for the hold time.
127. Traverse every directed edge twice in daylight-equivalent lighting and twice in the actual demo lighting without touching the robot.
128. Summon from every checkpoint to every other checkpoint at least once; any failure means the graph/demo is not ready.

## Power, heat, payload, and 20-minute acceptance

129. Fully charge the pack only with its matching charger; after resting, verify approximately 12.6 V and no swelling, damage, odor, or heat.
130. Measure battery-side current with wheels lifted, forward on the floor, strafe, rotate, blocked-start for less than one second, and with final payload.
131. Require normal sustained battery current to stay at or below 3 A because the selected fuse and small SM-style connector are the present limit.
132. If the 3 A fuse opens during normal motion, do not install a larger fuse until the exact battery BMS, connector, lead, switch, and motor-stall ratings are verified.
133. Record motor-rail voltage under the worst normal floor maneuver; investigate a rail below 5.8 V or repeated Uno/Pi resets.
134. Weigh the complete robot and keep it below the chassis maker's claimed 1500 g capacity with margin.
135. Run the final route continuously for 20 minutes with the intended payload and network.
136. At 5, 10, 15, and 20 minutes record battery, connector, XL4015, L298N, and motor temperatures.
137. Stop for a battery above 45 °C, warm/darkened connector, motor odor, repeated thermal shutdown, or any wiring too hot to touch; use an infrared thermometer and keep L298N/XL4015 case surfaces below 70 °C as a conservative prototype gate.
138. After the run, switch off and measure the rested battery; stop demo use and recharge at 10.5 V rather than relying on unknown pack protection.
139. A simple 80%-usable capacity model predicts about 32 minutes at 3 A, 38 minutes at 2.5 A, and 48 minutes at 2 A; only the physical 20-minute payload test proves your pack/build.

## Demo-day operating sequence

140. Inspect tires, wheel screws, wires, fuse, switch, battery condition, camera aim, and all posters.
141. Measure the resting motor battery and confirm both motor rails are 6.3–6.7 V.
142. Power the Pi first, start the server, then power the motor system with wheels clear.
143. Confirm `/status` shows fresh camera, fresh telemetry, no stop flag, and a valid map.
144. Place the robot exactly at a commissioned checkpoint pose.
145. Put one trained operator beside the robot's physical switch for every run.
146. Have the user stand at a poster, scan its QR, verify the displayed checkpoint ID, and press **CALL FETCH**.
147. Keep the app foregrounded while the robot follows the route; never enter its path to demonstrate avoidance.
148. If behavior differs from commissioning, press app stop and then the physical switch—do not debug a moving robot.
149. At arrival, retrieve/load the robot only after it is fully stopped.
150. After the demo, switch motor power off, shut down the Pi normally, disconnect the battery, and charge/store it on a nonflammable surface under supervision.

## Go/no-go record

The build is **software-verified but not physically approved** until every blank
below contains measured evidence from this exact assembled robot.

Copy `commissioning/acceptance_template.json` to a new robot/date-specific JSON
file, enter the measured results, then run
`python3 tools/validate_commissioning.py commissioning/YOUR_RECORD.json`. The
blank template must fail; do not replace missing measurements with estimates.

| Gate | Pass evidence required | Result |
|---|---|---|
| Two XL4015 rails | 6.3–6.7 V idle and ≥5.8 V worst normal load | ___ |
| Logic rail | 4.8–5.2 V, no resets | ___ |
| Current/fuse | all sustained modes ≤3 A; 3 A fuse survives | ___ |
| Five sonars | 20/60/100 cm and installed cross-talk test pass | ___ |
| Motion primitives | F/B/L/R/CW/CCW correct, no unintended spin | ___ |
| Directed graph | every physical edge passes twice in demo lighting | ___ |
| Failure stops | camera, USB, phone, obstacle, cancel all pass | ___ |
| Arrival integrity | obstacle never equals arrival; target gate passes | ___ |
| Payload | total mass and floor traction pass | ___ |
| Runtime/thermal | 20 min pass with recorded temperatures | ___ |
| Network | private network covers entire route without isolation | ___ |
| Full summons | every source-to-destination call passes | ___ |

No source-code analysis or calculation can fill these physical results. Until
all rows pass, describe FETCH as an in-progress supervised prototype—not as a
validated mall robot.

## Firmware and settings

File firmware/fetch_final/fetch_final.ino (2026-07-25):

/*
 * FETCH FINAL — 4 steppers + 3 front sonars + fixed camera + Pi.
 *
 * MOTORS: identical to fetch_steppers (the user's proven wiring/kinematics).
 *   FL = X (2,5)  FR = Y (3,6)  RL = Z (4,7) POL -1  RR = A (12,A0)  EN 8
 *   Mix: FL = fwd+side  FR = fwd-side  RL = fwd-side  RR = fwd+side
 *   NOTE the +side on FL. Flipping it sends every diagonal down the wrong axis.
 *
 * SENSORS: A0 is RR's direction pin, so the echoes route around it and use
 *   A2 (Resume) instead — A2 is free now that Y-DIR lives on D6.
 *     TRIG (all three, one shared wire) -> D9   (X+ endstop)
 *     ECHO front       D10 (Y+ endstop)   ECHO left-front  A1 (Hold)
 *     ECHO right-front A2  (Resume)
 *     (rear pair removed - A3/A4 are free again)
 * SERVO: REMOVED. Camera is fixed-mount; D11 is free.
 * SPARE: D11, D13, A3, A4, A5, D0, D1
 *
 * SERIAL 115200
 *   v <vx> <vy> <w>   -100..100 each   vx fwd, vy right, w clockwise
 *   f b l r q e s     manual keys       + -   speed step
 *   m <corner> <spd>  one motor: 0=FL 1=FR 2=RL 3=RR
 *   t <n>             accepted, ignored (servo removed)
 *   c                 crab circle (~30 cm)      ?  report state
 *   OUT: "us f=52 lf=110 rf=0"  cm, 0 = no echo, ~11 Hz with 3 sensors
 *
 * SAFETY, both on the Uno so neither depends on WiFi:
 *   - v-mode stops if the Pi goes quiet 500 ms
 *   - forward motion refused under 25 cm front clearance
 */
#include <AccelStepper.h>
#include <math.h>

AccelStepper FL(AccelStepper::DRIVER, 2, 5);    // X  top-left
AccelStepper FR(AccelStepper::DRIVER, 3, 6);    // Y  top-right
AccelStepper RL(AccelStepper::DRIVER, 4, 7);    // Z  bottom-left
AccelStepper RR(AccelStepper::DRIVER, 12, A0);  // A  bottom-right (A0 = Abort)
AccelStepper* M[4] = { &FL, &FR, &RL, &RR };
const float POL[4] = { +1, +1, -1, +1 };        // RL inverted in hardware

const int ENABLE_PIN = 8;
// Steps per rev depends on the MS1/MS2/MS3 jumpers under each A4988:
//   no jumpers = 200 (full step, loudest)   1/2 = 400   1/4 = 800
//   1/8 = 1600   1/16 = 3200 (quietest, but needs a high pulse rate)
// Microstepping is the real cure for stepper noise. Change this to match
// the jumpers you fit, or the speed scale will be wrong by that factor.
const float STEPS_PER_REV = 200.0;
const float WHEEL_CIRC_M  = 0.0600 * M_PI;      // 60 mm wheels

// Steppers have loud and quiet speed bands (mechanical resonance), so the
// top rate is tunable at runtime with 'k <steps/s>' - no reflash needed to
// hunt for the quiet spot. Raised from 318 to give real headroom.
float MAX_SPS = 520.0;
const float MAX_SPS_CEILING = 1400.0;           // beyond this it just stalls

// Crab circle, 2 ft radius.
//   Peak wheel rate = amp*sqrt(2)*MAX_SPS and steppers STALL if commanded
//   above what they can start at. Your original sketch proved 264 steps/s,
//   so the lap time is chosen to land there. A shorter lap = faster = stall.
//   amp is also capped at 1/sqrt(2) so setVel()'s normaliser never clips the
//   sweep; clipping would flatten the fast quadrants into an oval.
const float CIRCLE_RADIUS_M = 0.3048;           // 1 ft radius = 2 ft ACROSS
const float SECONDS_PER_LAP = 11.0;             // -> ~261 steps/s peak
const float CRAB_RAMP_S     = 0.8;              // ease in/out, no stall on start
const int   CRAB_SLICE_MS   = 5;                // 4400 vector updates per lap

const int TRIG = 9;
// Three FRONT sensors only. The two rear ones were dropped: the robot never
// reverses autonomously, so rear echoes cost scan time (each ping blocks up
// to the echo timeout) and bought nothing. Fewer sensors = faster loop = the
// front reading, which is the one the veto depends on, refreshes sooner.
const int NUS = 3;
const int ECHO[NUS] = { 10, A1, A2 };           // f, lf, rf
const char* USNAME[NUS] = { "f", "lf", "rf" };
const int FRONT = 0, VETO_CM = 25;
// The front-obstacle veto is OFF until the sensors are proven. An interlock
// fed by garbage data just blocks legitimate driving: a rail glitch pinned
// the front reading at 5 cm and forward stopped working entirely.
//   Armed by default now that the sensors read reliably. 'g 0' disarms.
//   Needs two consecutive close reads
//   plus a plausible distance (HC-SR04 cannot resolve under ~2 cm).
bool guardOn = true;    // obstacle avoidance armed at boot
int  frontHits = 0;
const int VETO_MIN_CM = 3, VETO_CONFIRM = 2;
int usCM[NUS] = { 0, 0, 0 };
int usIdx = 0;
// Median-of-3 per sensor. A shared TRIG means all five ping at once, so a
// sensor occasionally hears a neighbour's burst before its own return and
// reports a wild short value. A median rejects that single outlier while
// still tracking real movement.
int usHist[NUS][3] = {{0}};
byte usSlot[NUS] = { 0, 0, 0 };

int median3(int a, int b, int c) {
  if (a > b) { int t = a; a = b; b = t; }
  if (b > c) { int t = b; b = c; c = t; }
  if (a > b) { int t = a; a = b; b = t; }
  return b;
}


float curVX = 0, curVY = 0, curW = 0;
int speedPct = 60;
bool vMode = false;
unsigned long lastV = 0, lastPing = 0, lastReport = 0;
char line[40];
byte lineLen = 0;

// A stepper cannot START at its running speed. Pull-in torque collapses with
// rate, so commanding 0 -> 520 sps in one step makes a loaded wheel slip
// instead of turn. Whichever wheels slip, the robot rotates: on a strafe all
// four are fighting roller friction, so it shows up there first and worst.
// Targets are therefore ramped toward, not jumped to.
float wheelTgt[4] = {0, 0, 0, 0};    // what the mix asked for, sps
float wheelCur[4] = {0, 0, 0, 0};    // what the motors are actually running
unsigned long lastSlewUs = 0;
// Full scale in ~0.13 s. The first 20 ms tick asks for about 80 sps, still
// far inside pull-in, but the robot answers the button quickly enough that it
// does not feel laggy. 'a' lowers it if a wheel ever slips again.
float SLEW_SPS_PER_S = 4000.0;

void setVel(float vx, float vy, float w) {
  if (guardOn && vx > 0 && frontHits >= VETO_CONFIRM) vx = 0;   // veto
  curVX = vx; curVY = vy; curW = w;
  float s[4];
  s[0] = vx + vy + w;      // FL
  s[1] = vx - vy - w;      // FR
  s[2] = vx - vy + w;      // RL
  s[3] = vx + vy - w;      // RR
  float mx = 0;
  for (int i = 0; i < 4; i++) mx = max(mx, fabs(s[i]));
  if (mx > 1.0) for (int i = 0; i < 4; i++) s[i] /= mx;
  for (int i = 0; i < 4; i++) wheelTgt[i] = POL[i] * s[i] * MAX_SPS;
}

void applySlew() {
  unsigned long now = micros();
  float dt = (now - lastSlewUs) / 1000000.0f;
  lastSlewUs = now;
  if (dt <= 0 || dt > 0.25f) dt = 0.01f;      // first call, or a long stall
  float step = SLEW_SPS_PER_S * dt;
  for (int i = 0; i < 4; i++) {
    float t = wheelTgt[i], c = wheelCur[i];
    bool opposing = (t > 0 && c < 0) || (t < 0 && c > 0);
    if (opposing) {
      // A full reversal is a bigger jump than starting from rest, so drop to
      // zero this tick and ramp up the other way from there.
      c = 0;
    } else if (fabs(t) <= fabs(c)) {
      // Slowing never stalls a stepper, and STOP has to stay instant.
      c = t;
    } else if (t - c >  step) {
      c += step;
    } else if (t - c < -step) {
      c -= step;
    } else {
      c = t;
    }
    wheelCur[i] = c;
    M[i]->setSpeed(c);
  }
}

void runAll() { for (int i = 0; i < 4; i++) M[i]->runSpeed(); }

// pulseIn() blocks, so its timeout is stolen from stepper pulse generation.
// Standing still that costs nothing, so use the sensor's full ~4 m range;
// while driving, cap at ~1 m so the stall stays an inaudible blip.
unsigned long echoTimeoutUs() {
  applySlew();      // step the wheels toward their target before running them

  bool moving = (fabs(curVX) + fabs(curVY) + fabs(curW)) > 0.05;
  return moving ? 6000UL : 23000UL;
}

void pingOne(int i) {
  digitalWrite(TRIG, LOW);  delayMicroseconds(4);
  digitalWrite(TRIG, HIGH); delayMicroseconds(10);
  digitalWrite(TRIG, LOW);
  unsigned long us = pulseIn(ECHO[i], HIGH, echoTimeoutUs());
  int raw = us ? (int)(us / 58) : 0;
  usHist[i][usSlot[i]] = raw;
  usSlot[i] = (usSlot[i] + 1) % 3;
  usCM[i] = median3(usHist[i][0], usHist[i][1], usHist[i][2]);
  if (i == FRONT) {
    bool close = (usCM[FRONT] >= VETO_MIN_CM && usCM[FRONT] < VETO_CM);
    frontHits = close ? frontHits + 1 : 0;
    if (guardOn && curVX > 0 && frontHits >= VETO_CONFIRM)
      setVel(0, curVY, curW);
  }
}

void crabCircle() {
  // The 'c' arrives as "c\n". Without this flush the trailing newline is
  // still buffered, the abort check below sees it on the very first pass,
  // and the circle cancels itself after one 5 ms slice -> a twitch.
  delay(5);
  while (Serial.available()) Serial.read();
  Serial.println("crab start");
  float V      = (2.0 * M_PI * CIRCLE_RADIUS_M) / SECONDS_PER_LAP;   // m/s
  float topMs  = MAX_SPS * WHEEL_CIRC_M / STEPS_PER_REV;   // current full-scale
  float amp    = min(V / topMs, 0.7071f);        // cap: keep peak <= 1.0
  unsigned long t0 = micros();
  float lapUs = SECONDS_PER_LAP * 1e6;
  while ((float)(micros() - t0) < lapUs) {
    float t   = (float)(micros() - t0) / 1e6;
    float ang = 2.0 * M_PI * t / SECONDS_PER_LAP;
    // ease in and out so the motors are never asked to start at full rate
    float ramp = min(1.0f, min(t / CRAB_RAMP_S,
                               (SECONDS_PER_LAP - t) / CRAB_RAMP_S));
    setVel(amp * ramp * sin(ang), amp * ramp * cos(ang), 0);  // body stays put
    unsigned long slice = millis();
    while (millis() - slice < CRAB_SLICE_MS) { runAll(); yield(); }
    // Don't consume the byte: break and let loop() parse it, so STOP works.
    if (Serial.available()) break;
  }
  setVel(0, 0, 0);
  Serial.println("crab done");
}

void handleLine() {
  line[lineLen] = 0;
  char c = line[0];
  if (c == 'v') {
    // strtol, NOT sscanf: newlib-nano here has no %f in scanf.
    char *p = line + 1;
    long v[3] = { 0, 0, 0 };
    for (int i = 0; i < 3; i++) v[i] = strtol(p, &p, 10);
    setVel(v[0] / 100.0f, v[1] / 100.0f, v[2] / 100.0f);
    vMode = true; lastV = millis();
  } else if (c == 't') {
    // Servo removed - the camera is bolted at a fixed angle now. The command
    // is still accepted so an older Pi build cannot wedge on an unknown key.
  } else if (c == 'k') {
    // k <steps/s> : set the full-scale wheel rate. Higher = faster, and the
    // noise changes sharply with it - sweep to find the quiet band.
    long v = strtol(line + 1, NULL, 10);
    if (v >= 60 && v <= (long)MAX_SPS_CEILING) {
      MAX_SPS = (float)v;
      setVel(curVX, curVY, curW);        // re-apply at the new scale
    }
    Serial.print("maxsps="); Serial.println(MAX_SPS);
  } else if (c == 'a') {
    // a <sps/s> : how hard the wheels are allowed to accelerate. Lower it if
    // a strafe still slips, raise it if the robot feels sluggish.
    long v = strtol(line + 1, NULL, 10);
    if (v >= 300 && v <= 20000) SLEW_SPS_PER_S = (float)v;
    Serial.print("slew="); Serial.println(SLEW_SPS_PER_S);
  } else if (c == 'g') {
    guardOn = (strtol(line + 1, NULL, 10) != 0);
    Serial.print("guard="); Serial.println(guardOn ? "ON" : "OFF");
  } else if (c == 'm') {
    char *p = line + 1;
    long idx = strtol(p, &p, 10);
    long spd = strtol(p, &p, 10);
    for (int i = 0; i < 4; i++) M[i]->setSpeed(0);
    if (idx >= 0 && idx < 4) M[idx]->setSpeed(POL[idx] * (spd / 100.0f) * MAX_SPS);
    curVX = curVY = curW = 0;
    vMode = false;
  } else {
    float s = speedPct / 100.0f; vMode = false;
    if      (c == 'f') setVel( s, 0, 0);
    else if (c == 'b') setVel(-s, 0, 0);
    else if (c == 'l') setVel(0, -s, 0);
    else if (c == 'r') setVel(0,  s, 0);
    else if (c == 'q') setVel(0, 0, -s);
    else if (c == 'e') setVel(0, 0,  s);
    else if (c == 's') setVel(0, 0, 0);
    else if (c == 'c') crabCircle();
    else if (c == '?') {
      Serial.print("vx="); Serial.print(curVX);
      Serial.print(" vy="); Serial.print(curVY);
      Serial.print(" w=");  Serial.print(curW);
      Serial.print(" spd="); Serial.print(speedPct);
      Serial.print(" guard="); Serial.print(guardOn ? "ON" : "OFF");
      Serial.print(" maxsps="); Serial.print(MAX_SPS);
      Serial.print(" m/s="); Serial.println(MAX_SPS * WHEEL_CIRC_M / STEPS_PER_REV);
    }
    else if (c == '+' || c == '-')
      speedPct = constrain(speedPct + (c == '+' ? 10 : -10), 20, 100);
  }
  lineLen = 0;
}

void setup() {
  Serial.begin(115200);
  pinMode(ENABLE_PIN, OUTPUT); digitalWrite(ENABLE_PIN, LOW);
  // setMaxSpeed must cover the ceiling, not today's MAX_SPS, or a later
  // 'k' command would be silently clamped to the old limit.
  for (int i = 0; i < 4; i++) {
    M[i]->setMaxSpeed(MAX_SPS_CEILING * 1.6);
    M[i]->setSpeed(0);
  }
  pinMode(TRIG, OUTPUT); digitalWrite(TRIG, LOW);
  for (int i = 0; i < NUS; i++) pinMode(ECHO[i], INPUT_PULLDOWN);  // unwired = 0, not noise
  Serial.println("FETCH FINAL READY");
}

void loop() {
  while (Serial.available()) {
    char ch = Serial.read();
    if (ch == '\n' || ch == '\r') { if (lineLen) handleLine(); }
    else if (lineLen < sizeof(line) - 1) {
      line[lineLen++] = ch;
      if (lineLen == 1 && strchr("fblrqsec+-?", ch)) handleLine();
    }
  }

  applySlew();      // step the wheels toward their target before running them

  bool moving = (fabs(curVX) + fabs(curVY) + fabs(curW)) > 0.05;
  // >=60 ms between TRIG pulses: with one shared trigger wire the tick rate
  // IS each sensor's re-trigger rate. 30 ms was re-firing them mid-echo.
  if (millis() - lastPing >= (unsigned long)(moving ? 150 : 70)) {
    lastPing = millis();
    pingOne(usIdx);
    usIdx = (usIdx + 1) % 5;
  }

  if (millis() - lastReport >= 140) {
    lastReport = millis();
    Serial.print("us");
    for (int i = 0; i < NUS; i++) {
      Serial.print(' '); Serial.print(USNAME[i]);
      Serial.print('='); Serial.print(usCM[i]);
    }
    Serial.println();
  }

  if (vMode && millis() - lastV > 500) { setVel(0, 0, 0); vMode = false; }

  runAll();
  yield();
}

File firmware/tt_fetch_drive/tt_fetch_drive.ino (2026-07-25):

/*
 * FETCH TT PRODUCTION FIRMWARE
 * Arduino Uno R4 + two L298N modules + four TT motors + five HC-SR04.
 *
 * Pi -> Uno (USB CDC, 115200 baud):
 *   V <vx_mm_s> <vy_mm_s> <omega_deg_s>\n
 *   E\n   latch emergency stop
 *   C\n   clear latched emergency stop
 *
 * Uno -> Pi, 10 Hz:
 *   S <front> <left_front> <right_front> <left_rear> <right_rear> <estop>\n
 * Distances are centimetres; 0 means no echo within 2 m. estop is 0 or 1.
 * A 500 ms command watchdog and the local ultrasonic veto stop the motors.
 *
 * MOTOR PIN MAP (remove all four ENA/ENB jumper caps):
 *   M1 PWM D5  IN1 D2   IN2 D4
 *   M2 PWM D6  IN1 D7   IN2 D8
 *   M3 PWM D9  IN1 D12  IN2 D13
 *   M4 PWM D10 IN1 A0   IN2 A1
 *
 * SONAR PIN MAP:
 *   all five TRIG -> D3
 *   front ECHO D11; left-front A2; right-front A3;
 *   left-rear A4; right-rear A5
 *
 * The shared trigger is a pin-count compromise forced by direct L298N control.
 * All echo pulses are captured concurrently (never sequential blocking reads).
 * Every module is triggered once per 65 ms, satisfying the HC-SR04 >60 ms
 * repeat-cycle guidance. Physical cross-talk testing is still mandatory.
 */

#include <Arduino.h>
#include <math.h>
#include <stdio.h>
#include <string.h>

const uint8_t PWM_PIN[4] = {5, 6, 9, 10};
const uint8_t IN1_PIN[4] = {2, 7, 12, A0};
const uint8_t IN2_PIN[4] = {4, 8, 13, A1};

// CORNER[FL, FR, RL, RR] gives the M1..M4 index at that corner.
const uint8_t CORNER[4] = {0, 1, 2, 3};
// Change a sign only after the one-wheel commissioning test.
const int8_t POLARITY[4] = {+1, +1, +1, +1};
const float TRIM[4] = {1.00f, 1.00f, 1.00f, 1.00f};

const uint8_t TRIG_PIN = 3;
const uint8_t ECHO_PIN[5] = {11, A2, A3, A4, A5};
enum SonarIndex { FRONT = 0, LEFT_FRONT = 1, RIGHT_FRONT = 2,
                  LEFT_REAR = 3, RIGHT_REAR = 4 };

const float MAX_LINEAR_MM_S = 250.0f;
const float MAX_OMEGA_DEG_S = 120.0f;
const int MIN_MOVING_PWM = 68;
const uint32_t COMMAND_WATCHDOG_MS = 500;
const uint32_t SONAR_PERIOD_MS = 65;
const uint32_t SONAR_TIMEOUT_US = 12000;  // about 2.0 m round trip
const uint32_t MOTOR_TICK_MS = 10;
const int PWM_SLEW_PER_TICK = 6;          // ~0.43 s from 0 to full

const int FRONT_STOP_CM = 60;
const int SIDE_STOP_CM = 35;
const int ROTATE_STOP_CM = 20;

int targetPwm[4] = {0, 0, 0, 0};
int actualPwm[4] = {0, 0, 0, 0};
int sonarCm[5] = {0, 0, 0, 0, 0};
uint16_t sonarHistory[5][3] = {};
uint8_t sonarHistoryCount[5] = {0, 0, 0, 0, 0};
uint8_t sonarHistoryPos[5] = {0, 0, 0, 0, 0};
uint8_t completedSonarFrames = 0;

float requestedVx = 0.0f;
float requestedVy = 0.0f;
float requestedOmega = 0.0f;
bool obstacleStop = true;   // motion remains inhibited through startup samples
bool latchedEstop = false;
bool velocityMode = false;

uint32_t lastCommandMs = 0;
uint32_t lastSonarMs = 0;
uint32_t lastReportMs = 0;
uint32_t lastMotorTickMs = 0;

char lineBuffer[64];
uint8_t lineLength = 0;

static int moveToward(int value, int target, int amount) {
  if (value < target) return min(value + amount, target);
  if (value > target) return max(value - amount, target);
  return value;
}

static int medianOfAvailable(uint16_t *values, uint8_t count) {
  uint16_t v[3] = {201, 201, 201};
  for (uint8_t i = 0; i < count; ++i) v[i] = values[i];
  for (uint8_t i = 0; i < count; ++i) {
    for (uint8_t j = i + 1; j < count; ++j) {
      if (v[j] < v[i]) { uint16_t t = v[i]; v[i] = v[j]; v[j] = t; }
    }
  }
  return v[count / 2];
}

static bool nearObstacle(uint8_t index, int thresholdCm) {
  return sonarCm[index] > 0 && sonarCm[index] <= thresholdCm;
}

static bool blockedFor(float vx, float vy, float omega) {
  if (completedSonarFrames < 3) return true;
  if (vx > 5.0f && nearObstacle(FRONT, FRONT_STOP_CM)) return true;
  if (vx < -5.0f && (nearObstacle(LEFT_REAR, SIDE_STOP_CM) ||
                     nearObstacle(RIGHT_REAR, SIDE_STOP_CM))) return true;
  if (vy < -5.0f && (nearObstacle(LEFT_FRONT, SIDE_STOP_CM) ||
                     nearObstacle(LEFT_REAR, SIDE_STOP_CM))) return true;
  if (vy > 5.0f && (nearObstacle(RIGHT_FRONT, SIDE_STOP_CM) ||
                    nearObstacle(RIGHT_REAR, SIDE_STOP_CM))) return true;
  if (fabsf(omega) > 5.0f &&
      (nearObstacle(FRONT, ROTATE_STOP_CM) ||
       nearObstacle(LEFT_FRONT, ROTATE_STOP_CM) ||
       nearObstacle(RIGHT_FRONT, ROTATE_STOP_CM) ||
       nearObstacle(LEFT_REAR, ROTATE_STOP_CM) ||
       nearObstacle(RIGHT_REAR, ROTATE_STOP_CM))) return true;
  return false;
}

static int normalizedToPwm(float value, uint8_t motorIndex) {
  float magnitude = fabsf(value) * TRIM[motorIndex];
  if (magnitude < 0.02f) return 0;
  magnitude = constrain(magnitude, 0.0f, 1.0f);
  int pwm = MIN_MOVING_PWM + (int)lroundf(magnitude * (255 - MIN_MOVING_PWM));
  return value < 0.0f ? -pwm : pwm;
}

static void stopTargets() {
  for (uint8_t i = 0; i < 4; ++i) targetPwm[i] = 0;
}

static void setVelocity(float vxMmS, float vyMmS, float omegaDegS) {
  requestedVx = constrain(vxMmS, -MAX_LINEAR_MM_S, MAX_LINEAR_MM_S);
  requestedVy = constrain(vyMmS, -MAX_LINEAR_MM_S, MAX_LINEAR_MM_S);
  requestedOmega = constrain(omegaDegS, -MAX_OMEGA_DEG_S, MAX_OMEGA_DEG_S);
  obstacleStop = blockedFor(requestedVx, requestedVy, requestedOmega);
  if (latchedEstop || obstacleStop) {
    stopTargets();
    return;
  }

  float x = requestedVx / MAX_LINEAR_MM_S;
  float y = requestedVy / MAX_LINEAR_MM_S;
  float w = requestedOmega / MAX_OMEGA_DEG_S;
  float wheel[4] = {
    x - y - w,  // front-left
    x + y + w,  // front-right
    x + y - w,  // rear-left
    x - y + w   // rear-right
  };
  float maximum = 1.0f;
  for (uint8_t i = 0; i < 4; ++i) maximum = max(maximum, fabsf(wheel[i]));
  for (uint8_t corner = 0; corner < 4; ++corner) {
    uint8_t motor = CORNER[corner];
    targetPwm[motor] = normalizedToPwm(wheel[corner] / maximum, motor);
  }
}

static void writeMotor(uint8_t motor, int pwm) {
  pwm = constrain(pwm * POLARITY[motor], -255, 255);
  if (pwm == 0) {
    analogWrite(PWM_PIN[motor], 0);
    digitalWrite(IN1_PIN[motor], LOW);
    digitalWrite(IN2_PIN[motor], LOW);
    return;
  }
  digitalWrite(IN1_PIN[motor], pwm > 0 ? HIGH : LOW);
  digitalWrite(IN2_PIN[motor], pwm > 0 ? LOW : HIGH);
  analogWrite(PWM_PIN[motor], abs(pwm));
}

static void serviceMotors() {
  uint32_t now = millis();
  if (now - lastMotorTickMs < MOTOR_TICK_MS) return;
  lastMotorTickMs = now;
  for (uint8_t i = 0; i < 4; ++i) {
    actualPwm[i] = moveToward(actualPwm[i], targetPwm[i], PWM_SLEW_PER_TICK);
    writeMotor(i, actualPwm[i]);
  }
}
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

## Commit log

2026-07-25 2ft crab circle on the Uno, and make emergency stop actually stop
    Crab ran as a Python loop on the Pi that kept pushing velocities, so STOP was
    overridden milliseconds later. It now runs on the Uno where any incoming byte
    breaks it (without consuming the byte, so the stop command still parses).
    GUI eStop clears the repeat timer and held-key state, double-sends, and binds
    Escape. Circle is now 2 ft radius over a 16 s lap with 5 ms vector refreshes
    (3200 per lap) using the real 60 mm wheels.
    [can_crown.step, can_crown.stl, crown_legs.step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]
2026-07-25 Fix crab circle stalling: cap peak wheel rate and ease in/out
    Commanded 359 steps/s from a standstill, well past the 264 the motors are
    proven to start at, so they just buzzed. Lap is now 22 s (~261 steps/s peak),
    amplitude is capped at 1/sqrt(2) so setVel's normaliser never clips the sweep
    (clipping flattened the fast quadrants into an oval), and a 1.2 s ramp eases
    in and out. Also corrected fetch_final to 60 mm wheels.
    [fetch_final.ino, fetch_steppers.ino]
2026-07-25 Fix crab circle cancelling itself on the buffered newline
    'c\n' fired the routine while the newline was still queued, so the abort
    check saw it on the first pass and quit after one 5 ms slice - the twitch.
    Flush the buffer before starting and report start/done so a full lap can be
    verified remotely. Confirmed: 22.0 s lap end to end, and STOP still breaks
    it mid-lap.
    [fetch_final.ino, fetch_steppers.ino]
2026-07-25 Crab circle to 2 ft diameter, 11 s lap
    Was 2 ft radius (4 ft across). Halving the radius at the same safe wheel
    speed halves the lap: 11.0 s verified end to end, peak 261 steps/s.
2026-07-25 Flash-ready fetch_final: pulldowns on echo pins so unwired sensors read 0
    Floating echo inputs could return noise from pulseIn and spuriously trip the
    front-obstacle veto, blocking forward motion before the sensors are even
    wired. INPUT_PULLDOWN makes an unconnected pin read a clean zero.
    [fetch_final.ino]
2026-07-25 Make the front-obstacle veto opt-in and debounced
    An unstable 5V rail pinned the front sonar at a fake 5 cm, so the veto
    silently blocked all forward motion - the drivetrain was held hostage by a
    sensor that has never worked. The guard now defaults OFF and is armed with
    'g 1' once the sensors are trusted; when armed it needs two consecutive
    readings and ignores anything under 3 cm (below HC-SR04's real minimum).
    [fetch_final.ino, sonar_test.ino]
2026-07-25 Arm obstacle avoidance; live sensor bars and guard toggle in the GUI
    Veto defaults on now that readings are stable, with the median filter and
    70 ms trigger spacing behind it. GUI polls at 4 Hz and shows each sensor as
    a value plus a proportional bar, colour-banded (red under 25 cm = veto zone,
    amber under 50), with an em-dash for no-echo instead of a misleading 0.
    ARMED/OFF button toggles the veto live.
    [drive.py, fetch_final.ino, gui.py]
2026-07-25 Full perception stack: camera in the GUI, AprilTags, vision obstacle zones
    fetch_auto.py adds the autonomous flow (tag-seeking servo sweep, mecanum
    strafe-approach that keeps the tag in frame, sonar+vision fusion) and every
    stage degrades rather than fails, since the sonars are intermittent.
    Vision now lives inside the GUI process because only one process can hold
    /dev/video0, and it publishes an annotated MJPEG stream so the overlay is
    visible at the same IP as the controls. Camera auto-detects USB (C920) first,
    then CSI. Also fixed drive.py's reader, which used readline() with a 0.1 s
    timeout against a 140 ms report interval and so parsed only fragments.
    [drive.py, fetch_auto.py, gui.py]
2026-07-25 Autonomous 'go to art piece' inside the GUI, with safety precedence
    Autonomy had to move into the GUI process: only one process can hold the
    serial port and only one can hold /dev/video0, so a separate script meant
    stopping the GUI to demo. Tag buttons 0-4 now drive there autonomously.
    Approach strafes rather than spins - rotating to correct heading would swing
    the camera off the tag and lose it, which is the whole reason for mecanum.
    Safety precedence, all verified in-process: STOP aborts autonomy, manual
    driving aborts autonomy, re-tapping a tag cancels, sonar outranks vision for
    anything close, and a hard timeout stops it hunting forever.
    [autopilot.py, gui.py]
2026-07-25 Add cloudflared tunnel service for networks that isolate clients
    The conference network blocks device-to-device traffic entirely, so no local
    IP is reachable from a phone. The Pi dials out to Cloudflare instead and the
    phone meets it there. Quick tunnels mint a new URL per start, so the service
    logs to a fixed path where the current address can be read.
2026-07-25 Calibrated tag locations, 3 front sonars
    The robot has no encoders or IMU, so a room coordinate cannot be known and
    dead reckoning on mecanum wheels drifts immediately. Instead a calibration
    stores what a tag LOOKS like from the spot you parked on - area encodes
    distance, offset encodes bearing - and the autopilot drives until the live
    view matches. Error does not accumulate: every frame is a fresh fix against
    something bolted to the wall.
    Sonar drops to the front three; the rear pair only cost scan time since the
    robot never reverses autonomously. A3/A4 are free again.
    [autopilot.py, drive.py, fetch_final.ino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]
2026-07-25 Teach-and-repeat routes, set home, servo removed
    Replay is open-loop (no encoders) so it drifts; the tag is absolute but needs
    to already be in frame. Chaining them covers both gaps: replay gets close
    enough that the tag is big, the tag fixes what replay got wrong, and drift
    never carries across runs.
    Sonar 0 means no echo, never an obstacle - an unplugged sensor must not be
    able to freeze a replay. Servo removed entirely; camera is fixed-mount.
    [autopilot.py, drive.py, fetch_final.ino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]
2026-07-25 Route-only targets finish at the route end; serial auto-reconnect
    Teaching a route to a spot where the tag is not visible used to replay
    correctly and then drive back off it hunting for a tag that was never
    calibrated, failing at the timeout. A route with no calibration is now the
    whole plan and ends where it ends.
    Serial reconnects if the Uno re-enumerates (motor power cycling can brown it
    out onto a different ttyACM); previously the reader thread died and the GUI
    looked connected while every command went nowhere.
    [autopilot.py, drive.py]
2026-07-25 Checkpoint graph, phone-camera user page
    Calibration no longer needs the camera to see a tag. Drive to a spot with the
    controls and press mark N: everything driven since the last mark becomes the
    edge between them. Nodes are places, edges are the driving, and BFS finds the
    chain between any two.
    Edges run both ways because the robot is holonomic - reversing a leg is the
    segment list reversed with every velocity negated, which is a true inverse
    (verified: net displacement of forward+back is exactly zero). A car could not
    do this.
    is belief, not measurement, and only advances when a leg completes,
    so an aborted trip does not claim an arrival that never happened.
    The user page runs on a pho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
    [checkpoints.py, gui.py, navigator.py]
2026-07-25 Write printable tags into the repo, not the Desktop
    The Desktop path needs macOS permission this process does not reliably have,
    and the generated files kept vanishing between sessions.
2026-07-25 Route on driving seconds, not hop count
    Counting hops picks a single 40 s edge over two 5 s ones - wrong every time
    and it looks broken to anyone watching. Dijkstra weighted by taught driving
    time fixes it (verified: 8 s two-hop chosen over 40 s one-hop).
    Still only uses routes actually driven. The robot has no spatial model, so it
    cannot invent a shortcut between two checkpoints just because they are near
    each other - that edge has to be taught.
    [checkpoints.py]
2026-07-25 Rewrite README for the current build
    The old one described TT motors, L298N drivers, an iPhone app and five
    sensors, none of which the robot has.
2026-07-25 Add files via upload
    Add master chasis
    [Master Chasis.stl]
2026-07-25 Rename Master Chasis.stl to cad/Master Chasis.stl
    [Master Chasis.stl]
2026-07-25 Add files via upload
    Add lid
    [Trash can base lid.stl]
2026-07-25 Add files via upload
    Add ultra ring
    [Ultrasonic Ring.stl]
2026-07-25 Add files via upload
    pole
    [Supporting pole.stl]
2026-07-25 Add files via upload
    c290
    [C290 enclosure to servo.stl]
2026-07-25 Rename C290 enclosure to servo.stl to cad/C290 enclosure to servo.stl
    [C290 enclosure to servo.stl]
2026-07-25 Rename Servo enclosure ring.stl to cad /Servo enclosure ring.stl
    [Servo enclosure ring.stl]
2026-07-25 Rename Supporting pole.stl to cad /Supporting pole.stl
    [Supporting pole.stl]
2026-07-25 Rename Trash can base lid.stl to cad /Trash can base lid.stl
    [Trash can base lid.stl]
2026-07-25 Rename C290 enclosure to servo.stl to C290 enclosure to Servo.stl
    [C290 enclosure to Servo.stl]
2026-07-25 Health watchdog for the failure that does not crash
    systemd already restarts a service that dies. It cannot see the failure that
    actually took the robot down today: WiFi still associated, route out gone,
    which is what a captive portal expiring looks like. NetworkManager sees a
    healthy link and does nothing while Tailscale, Connect and the tunnel all go
    dark together.
    The watchdog checks reachability two ways before acting, since bouncing WiFi
    on a network that merely blocks ICMP would be a self-inflicted outage.
    Also fixes URL reading in bringup: cloudflared's log contains bytes grep
    treats as binary (suppressing matches), and it prints the URL several seconds
    before the tunnel is usable.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
2026-07-25 Merge the split cad folder, document the real printed parts
    A GitHub web upload created a second directory literally named 'cad ' with a
    trailing space, so three of the five parts were sitting in a folder nobody
    would find. All five are in cad/ now.
    README rewritten. The old one still described the previous design's generated
    parts, which are no longer in the repo, and its images pointed at files that
    had been deleted. Now it covers the parts we actually printed, with sizes and
    times, plus the eight hour build and the five hour print schedule.
    [Servo enclosure ring.stl, Supporting pole.stl, Trash can base lid.stl]
2026-07-25 Ramp wheel speed instead of jumping to it
    Steppers cannot start at their running speed. Pull-in torque collapses with
    rate, so commanding 0 to 520 sps in a single step made loaded wheels slip
    rather than turn. Whichever wheels slipped, the robot rotated.
    Strafe showed it first because all four wheels fight roller friction at once,
    and it got worse when the top speed went from 318 to 520.
    Ramping is per wheel, since a wheel is what stalls. Slowing and stopping stay
    instant because deceleration never stalls and STOP has to be immediate. A
    reversal routes through zero first, which is a bigger jump than starting from
    rest and would otherwise stall harder than the original bug.
    Verified off-bo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
    [fetch_final.ino]
2026-07-25 Serialize serial writes; stop duplicating them
    Two threads wrote to the port with no mutex: the keepalive at 10 Hz and an
    HTTP handler for every repeat of a held button. pyserial's write is not
    atomic, so lines interleaved and the Uno parsed the wreckage. Reproduced off
    the robot at 9.6% corrupt, producing commands like 'v 0 -60v 0 -60 0'. That
    is why a strafe did something random and then corrected itself: the next
    clean keepalive 100 ms later overwrote the garbage. Zero corrupt with the
    lock over the same run.
    The held button also re-posted an identical velocity every 200 ms purely to
    feed the deadman, while the keepalive was already refreshing the Uno. Only a
    real change is written now.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
    [drive.py, fetch_final.ino]
2026-07-25 Document what actually happened to the printed parts
    Everything was printed during the hackathon, so the CAD was finished in the
    same hours as the firmware. About 80 percent of parts needed cutting or
    modifying to fit, and three of the four chassis joints needed glue and repair
    to hold.
2026-07-25 Reframe the fabrication notes around rushed CAD
    The rework came from modeling in a hurry, not from a printing schedule. Adds
    the scrapped camera tilt, which is the clearest example: the mount never fit,
    the servo never moved reliably, and the feature was cut rather than fixed.
